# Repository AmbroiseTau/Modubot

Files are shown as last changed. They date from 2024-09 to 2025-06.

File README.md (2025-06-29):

<div style="display: flex; justify-content: center; margin: 0 auto; width: 100%;">
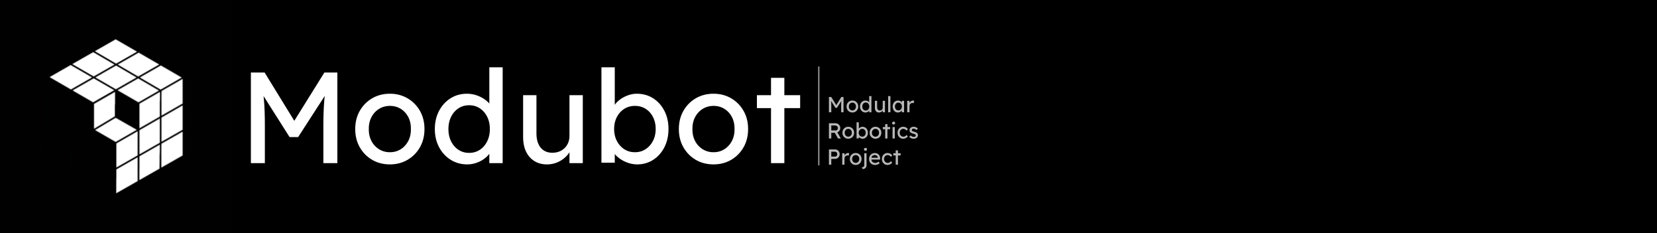
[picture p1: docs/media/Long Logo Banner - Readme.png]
Modubot: A Modular Robotics Project
  
</div>

---

**Modubot** is a modular robotics platform built around **cube-shaped modules**, each with a **dedicated PCB** designed for specific functions. These modules can serve as **regional controllers**, **motor controllers**, **sensor modules**, or other customizable components, allowing for a **flexible and adaptable robotic system**. The entire project is based on **STM32 microcontrollers**.

<div style="display: flex; justify-content: center; margin: 0 auto; width: 100%;">
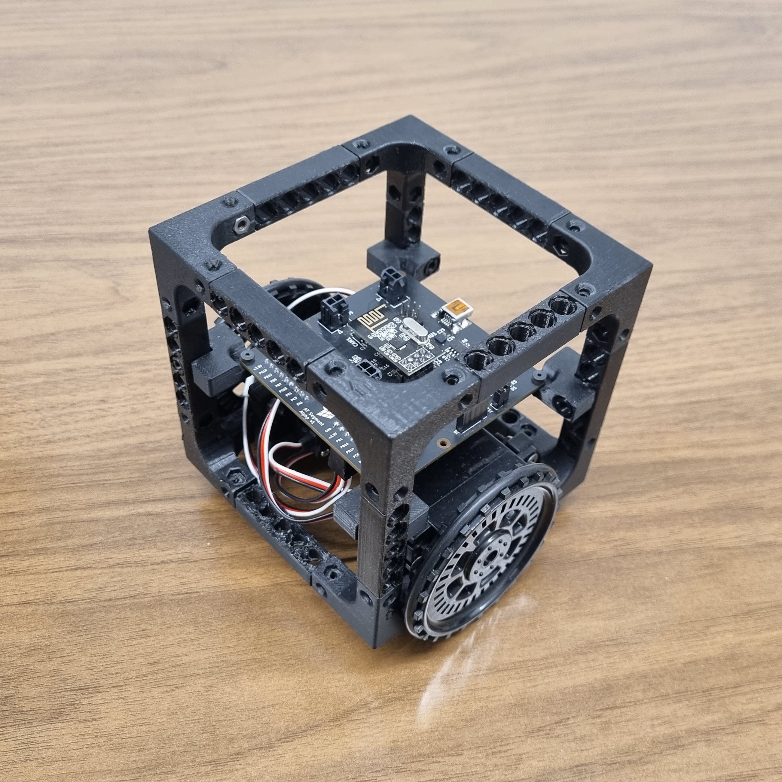
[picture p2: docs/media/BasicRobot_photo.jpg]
  
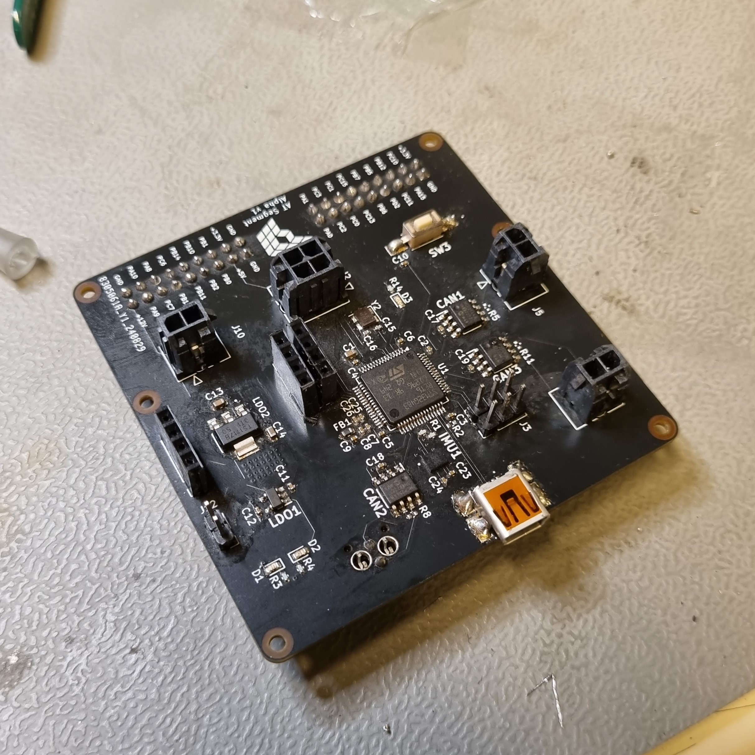
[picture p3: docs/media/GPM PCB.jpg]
  
</div>

---

## **Goal:**

The vision for Modubot is to create a **flexible, modular platform** that promotes **hands-on learning** and **skill development**. By using **cube-based modules**, each with a unique **electronic function**, Modubot acts as a **test platform** for experimenting with:

- **Protocols**
- **Circuits**
- **PCB architecture**
- **Firmware**

This project is a chance to **apply and refine engineering knowledge** while exploring **creative possibilities in robotics**.

---

## **Roadmap:**
1. **✅ Design First Ever Module (General Purpose) - Accomplished**
2. **✅ Create a Simple 2-Wheel Robot with Remote Operation - Accomplished**
3. **✅ Write Firmware for CAN-FD, IMU, UART GPS**
4. **✅ Create a 2 Degrees of Freedom Arm**
5. **🔲 Design a Brushed/Stepper/BLDC Motor Controller Module (MCM)**
6. **🔲 Create a Miniature Buggy Rover**
7. **🔲 Design 2nd Version of the General Purpose Module (GPM)**
8. **🔲 Design Modular Drone (1x GPM + 4x MCM)**

---

## **Current Status:**

### **STAGE 2:**
The current phase features a **2-wheeled robot** designed as a **proof of concept**. It tests the **General Purpose Module (GPM v1)** along with:

- **SPI to NRF24L01** (used for remote control)
- **Servo control**

However, the **continuous servos** faced **tuning issues**, preventing the robot from driving straight, highlighting the need to shift towards **PID-controlled DC motors with encoders** for precise control.

<div style="display: flex; justify-content: center; margin: 0 auto; width: 100%;">
  
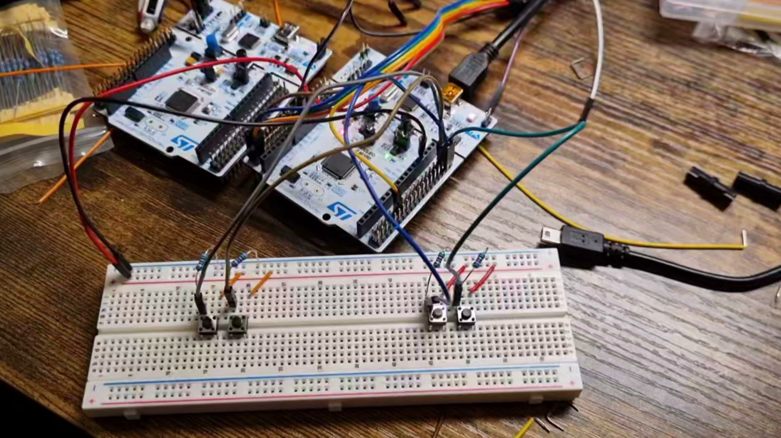
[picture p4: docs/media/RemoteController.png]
  
</div>

---

### **STAGE 1:**
The **first wave of designs** has been completed. The initial **PCB design** was kept **simple** to avoid unnecessary points of failure. It functions as intended, though there are some **design oversights**:

- It cannot handle **high current** (only 1-2 amps at 12V)
- Limited **resistance to back EMF**

These issues will be addressed in **version 2**, after learning more about system requirements.

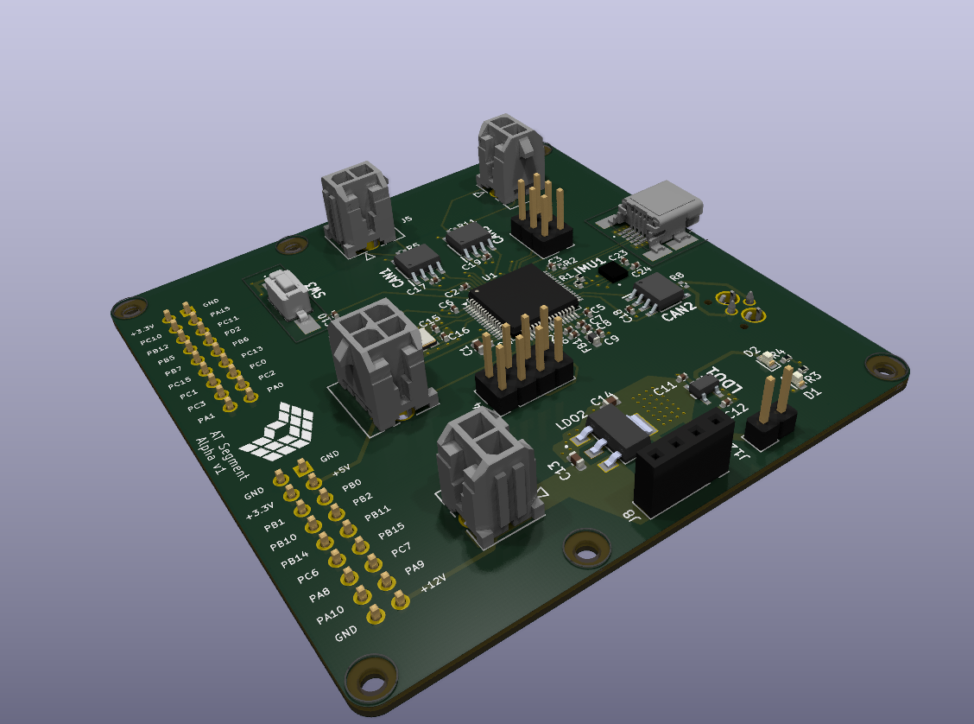
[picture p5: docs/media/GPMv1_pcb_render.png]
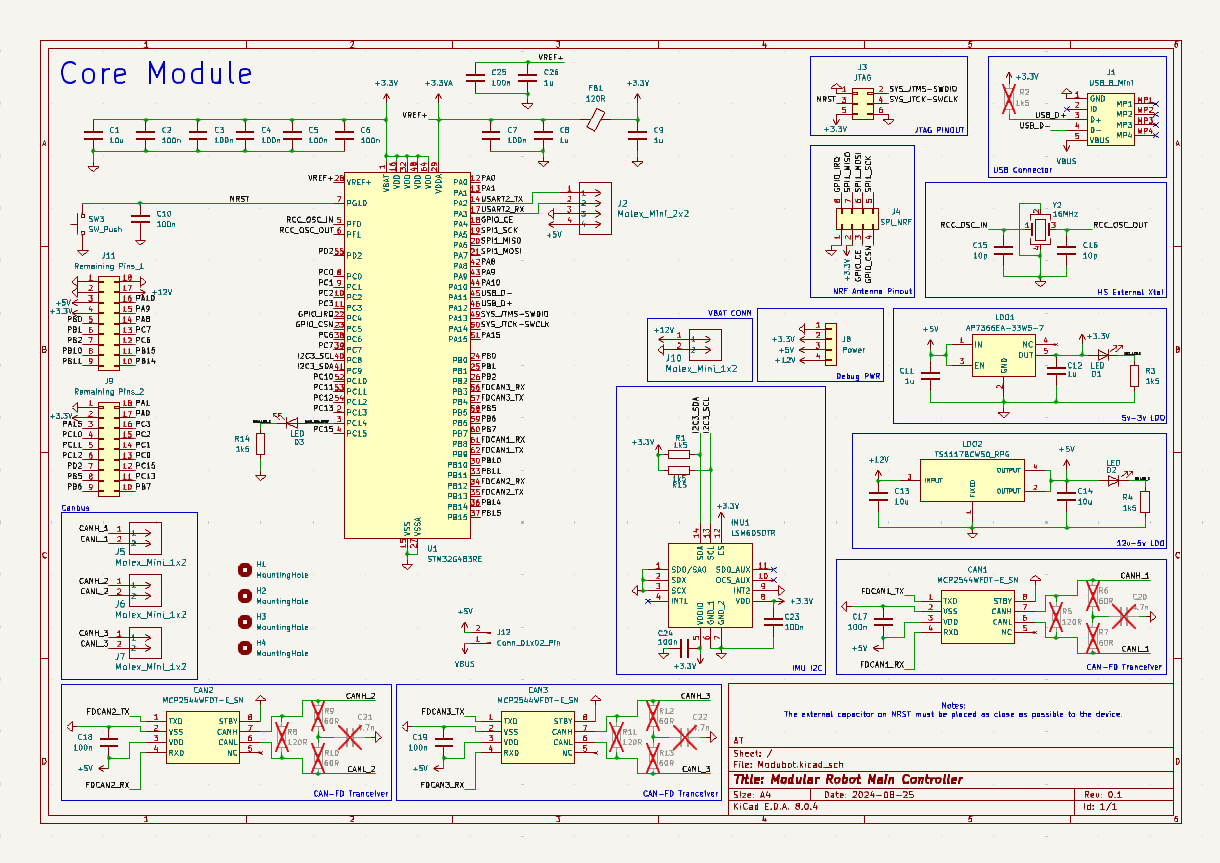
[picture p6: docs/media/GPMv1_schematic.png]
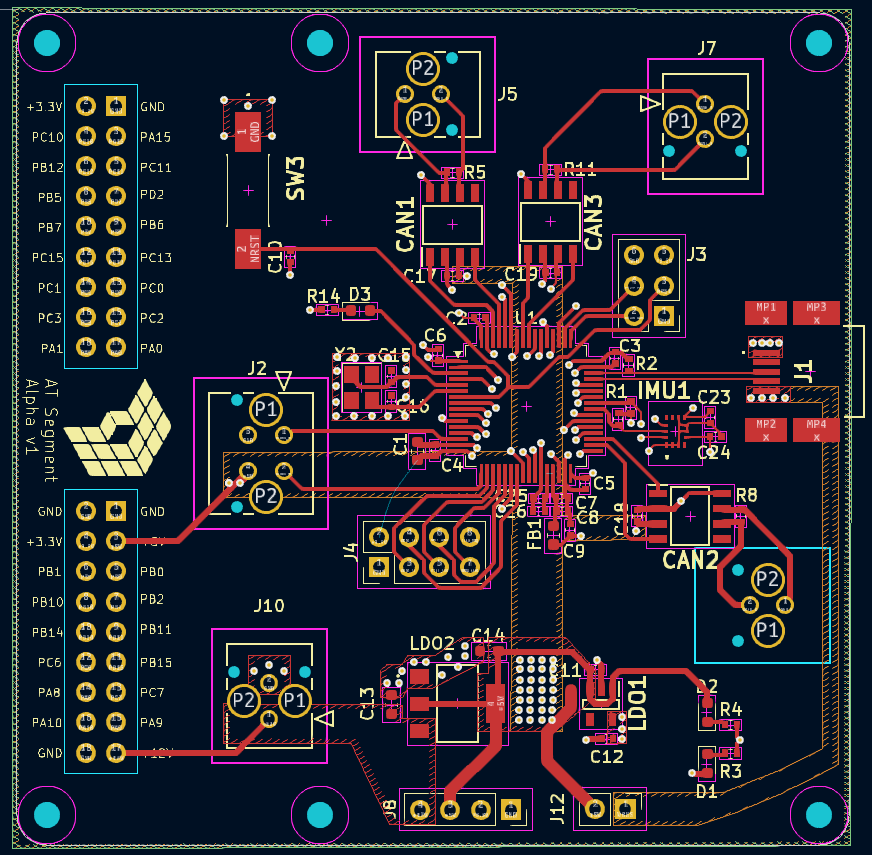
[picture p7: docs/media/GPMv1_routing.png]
   

The **3D-printed structure** has also been refined and is expected to remain unchanged unless major issues arise. For **quick connections** between modules and subcomponents (e.g., PCB bracket), **3D-printed Lego pins (scaled 1.25x)** are being used, and for more **permanent fixtures**, **M6 bolts** can be inserted in the same holes. Initially, **PETG** was used for printing, but due to **brittleness**, the material has been changed to **ABS**, which is more **ductile**.

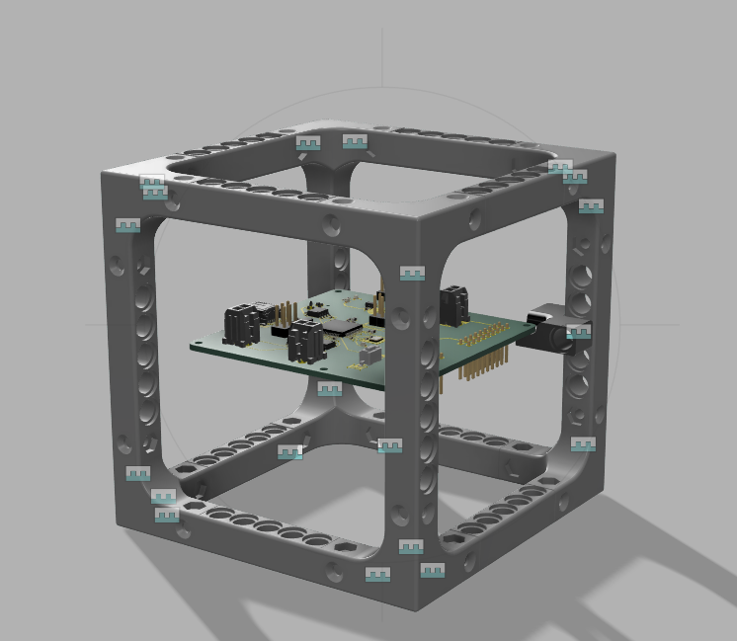
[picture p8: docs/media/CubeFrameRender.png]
CAD of the board


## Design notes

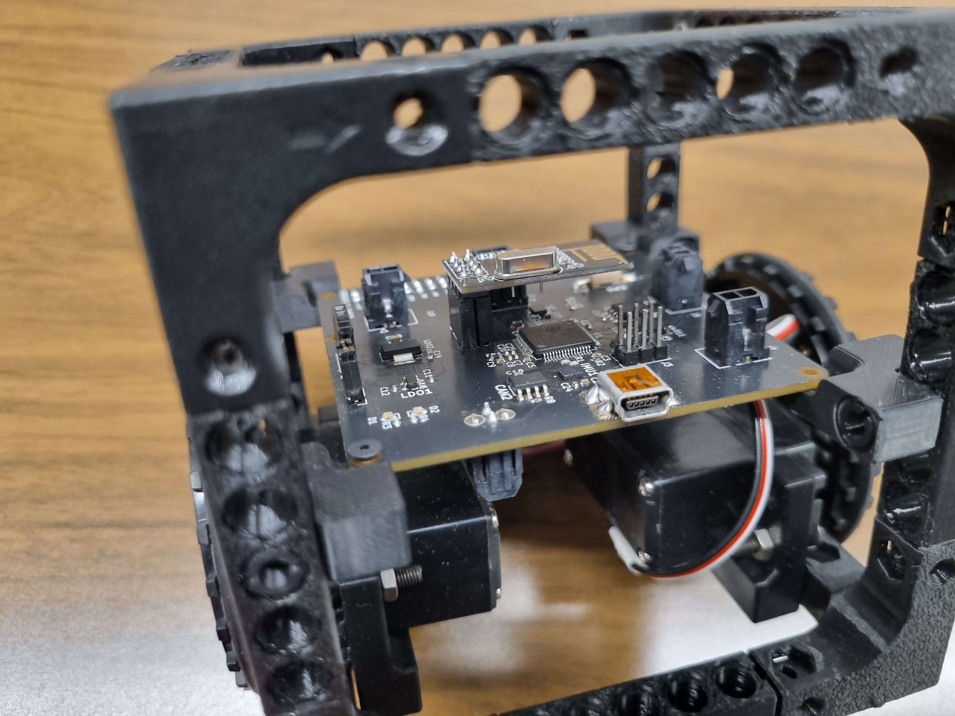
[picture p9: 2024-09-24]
docs/media/Closeup PCB.jpg

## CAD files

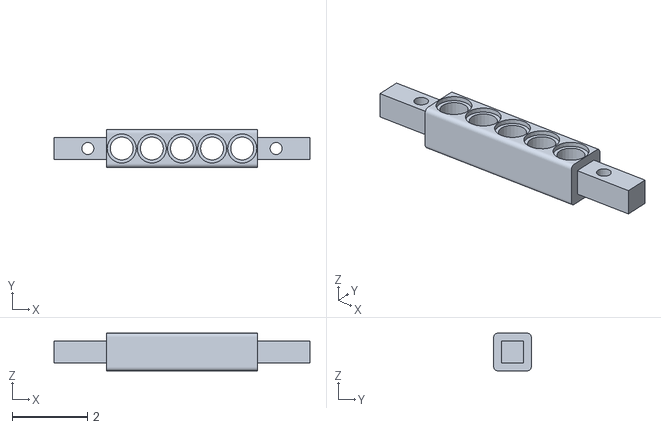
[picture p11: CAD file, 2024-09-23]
GridFrame v1/CAD/Edge Piece - Cube v1.obj
6.80 x 1.00 x 1.00

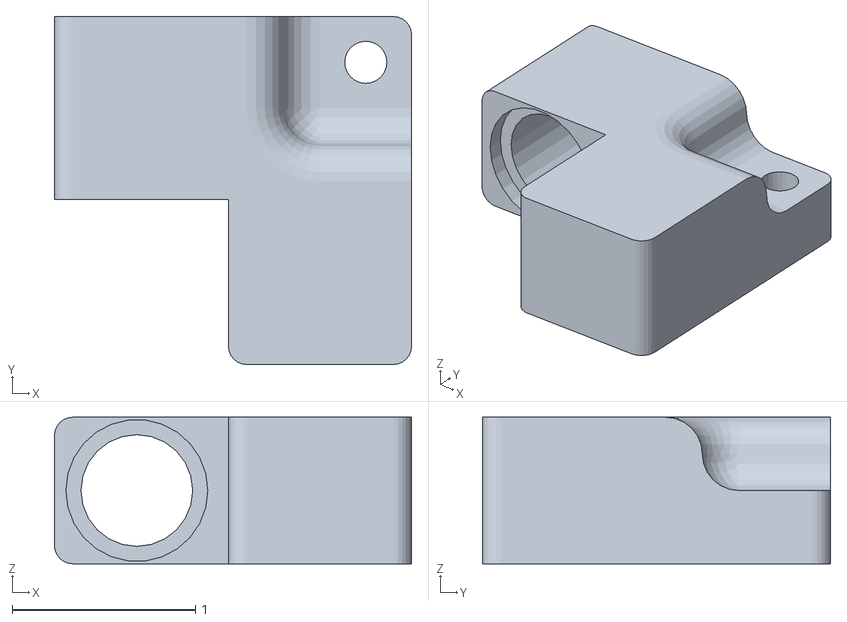
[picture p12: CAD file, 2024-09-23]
GridFrame v1/CAD/Board Bracket - Cube v1.obj
1.95 x 1.90 x 0.8

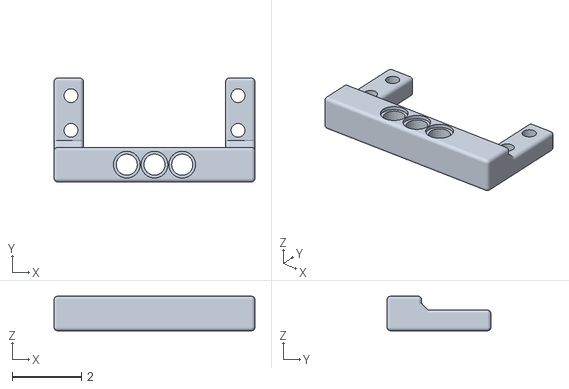
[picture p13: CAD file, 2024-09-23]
GridFrame v1/CAD/Servo Bracket - Cube v1.obj
5.80 x 3.00 x 1.00

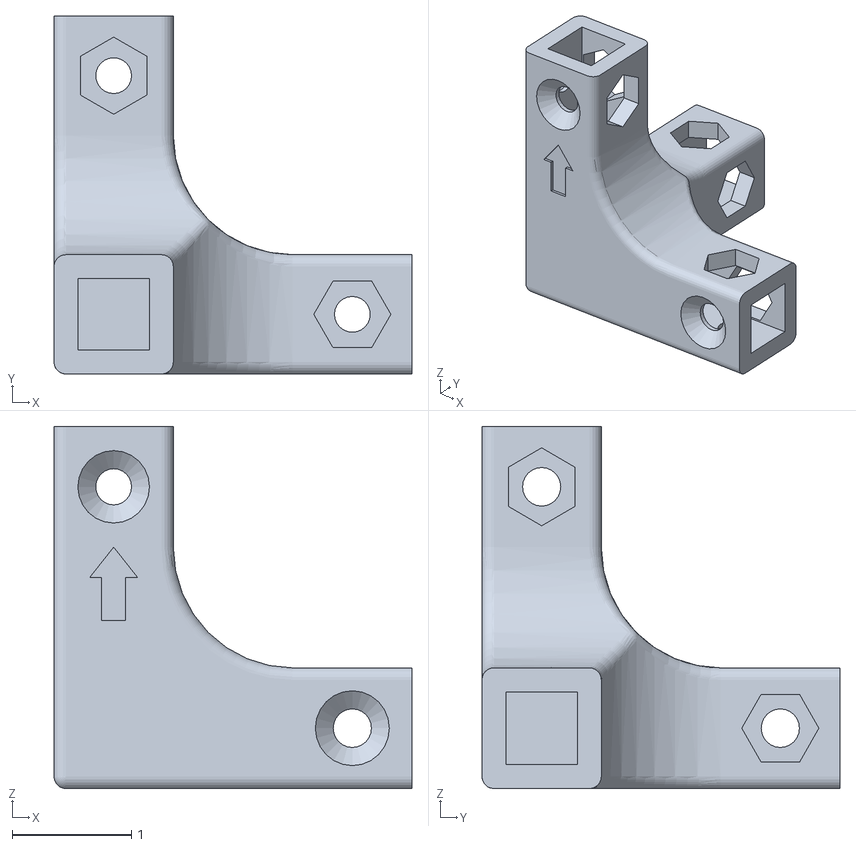
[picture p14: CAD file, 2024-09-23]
GridFrame v1/CAD/Corner Piece - Cube v1.obj
3.00 x 3.00 x 3.03

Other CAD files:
GridFrame v1/CAD/Board Bracket - Cube v1.f3d
GridFrame v1/CAD/Corner Piece - Cube v1.f3d
GridFrame v1/CAD/Edge Piece - Cube v1.f3d
GridFrame v1/CAD/Servo Bracket - Cube v1.f3d

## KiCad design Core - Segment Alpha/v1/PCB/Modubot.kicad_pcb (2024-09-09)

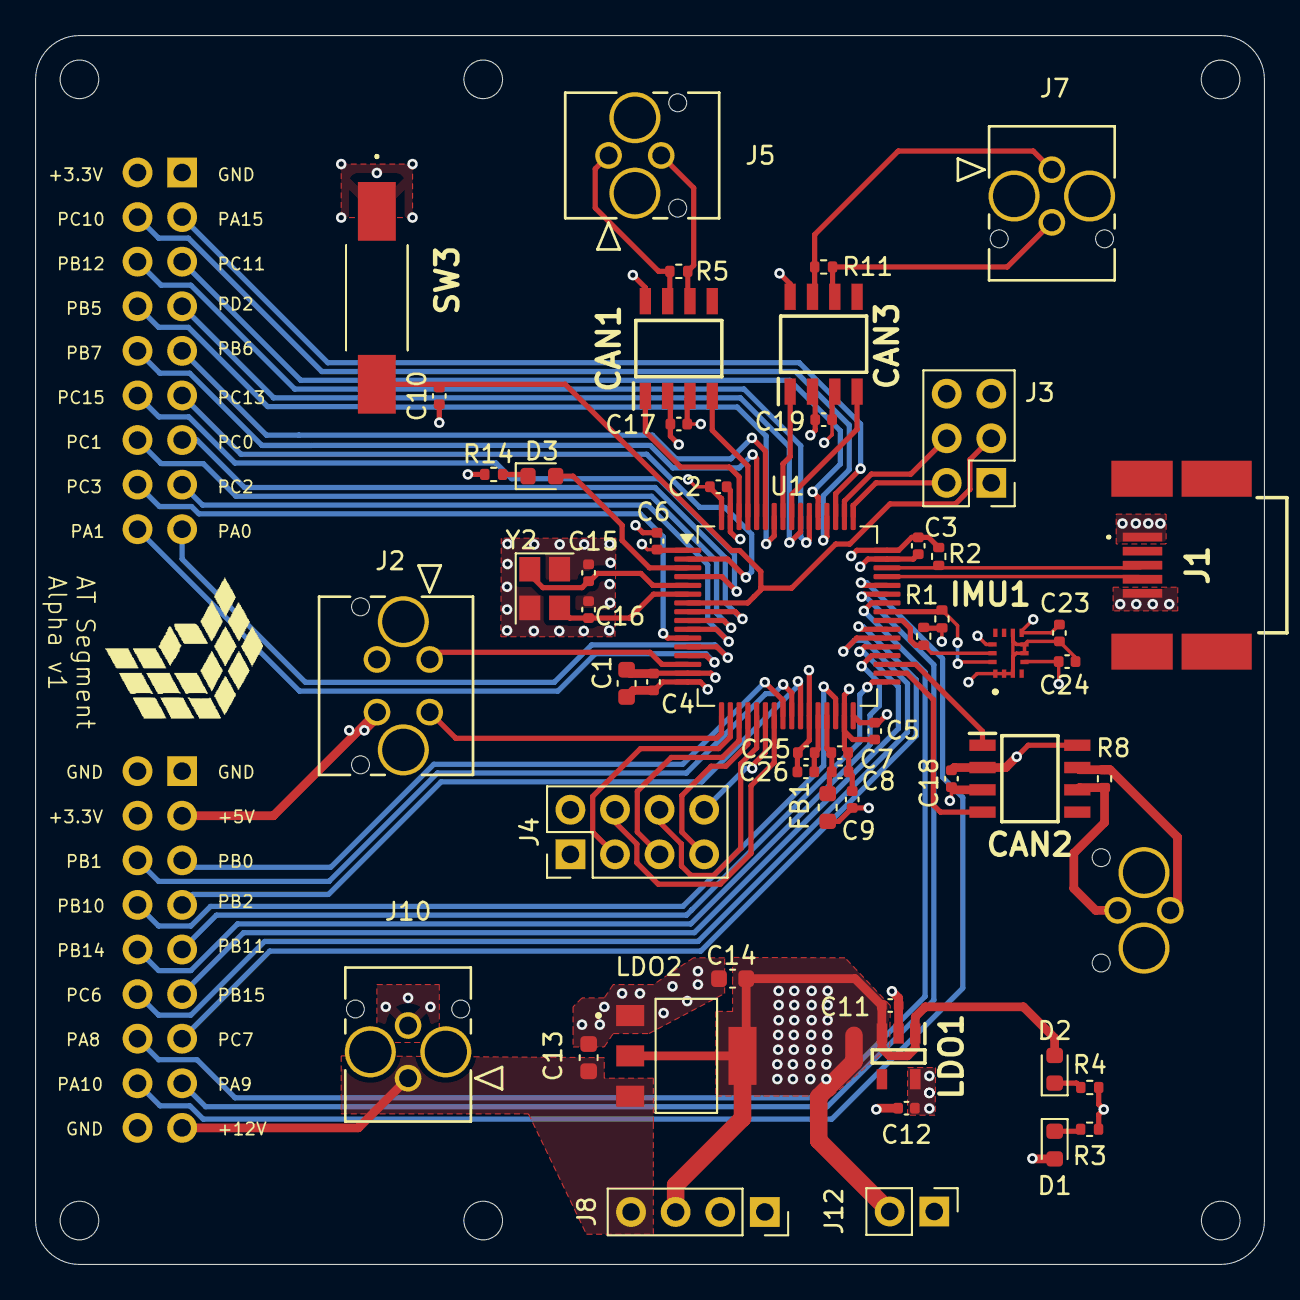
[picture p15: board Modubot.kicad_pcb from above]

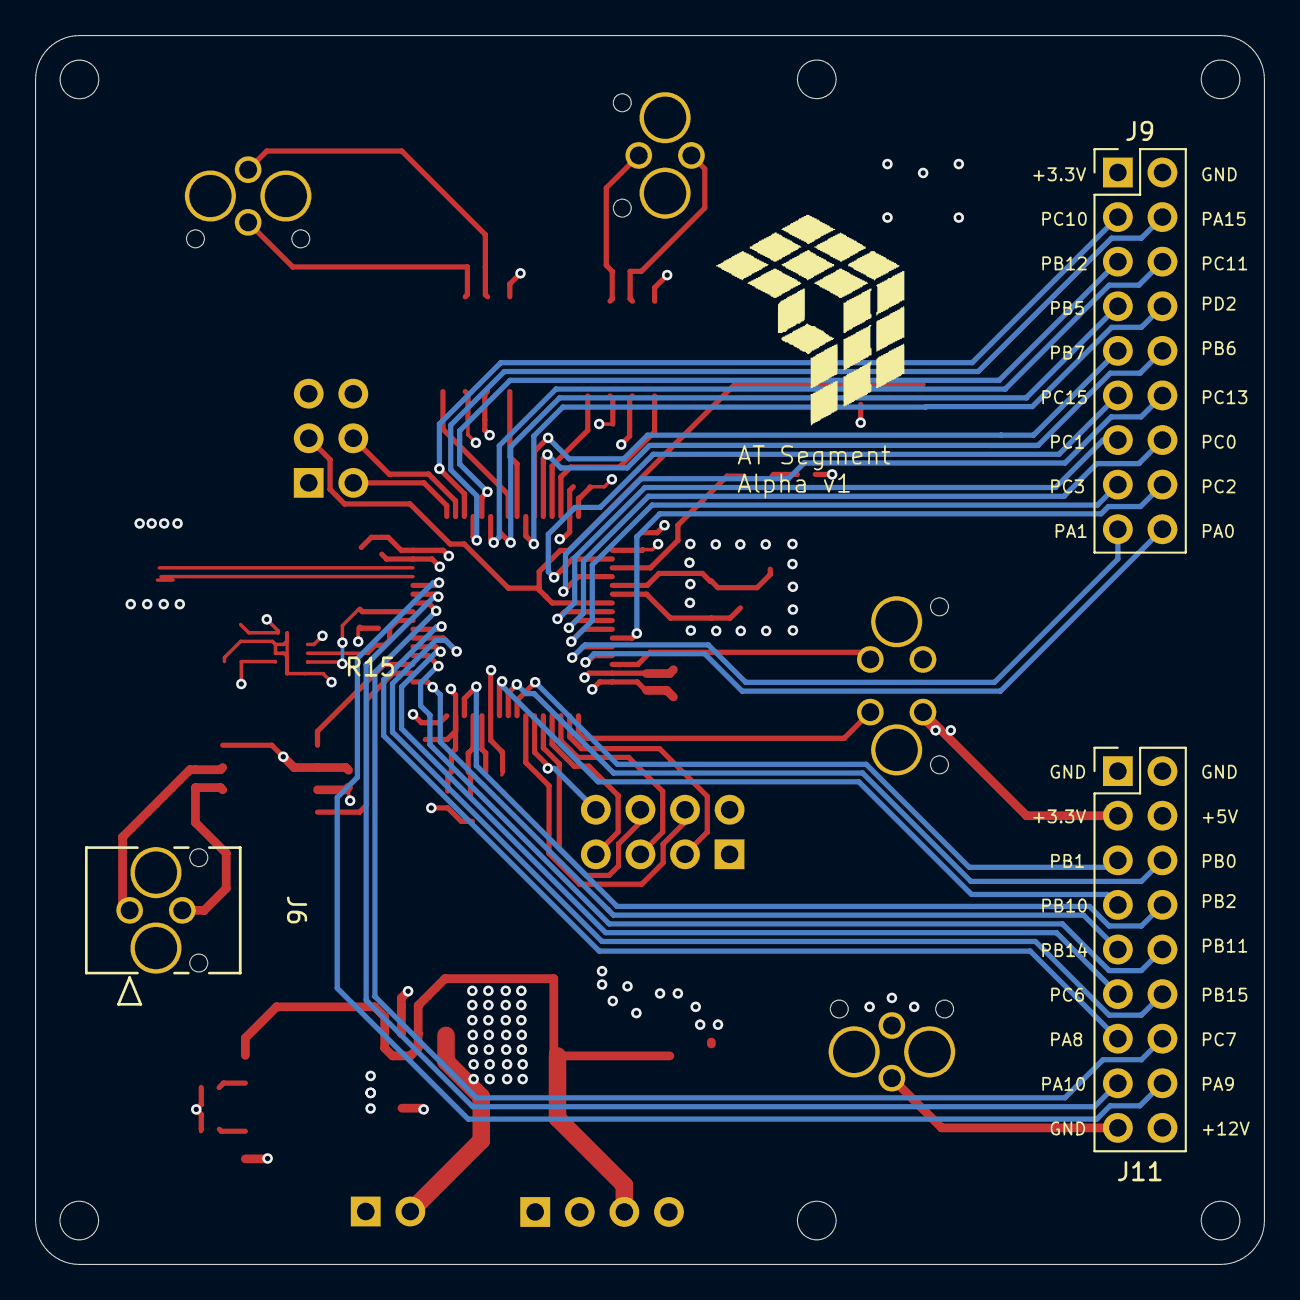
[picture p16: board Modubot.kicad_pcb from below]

Board: 4 copper layers, 70.0 x 70.0 mm, 63 parts (3 on the bottom side), 67 nets.

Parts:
C1, C13, C14: 10u; C_0603_1608Metric
C2, C3, C4, C5, C6, C7, C10, C17, C18, C19, C23, C24, C25: 100n; C_0402_1005Metric
C8, C9, C11, C12, C26: 1u; C_0402_1005Metric
C15, C16: 10p; C_0402_1005Metric
CAN1, CAN2, CAN3: MCP2544WFDT-E_SN; SOIC127P600X175-8N
D1, D2, D3: LED; LED_0603_1608Metric
FB1: 120R; L_0603_1608Metric
H1, H2, H3, H3#2, H4, H4#2: MountingHole; MountingHole_2.2mm_M2
IMU1: LSM6DSOTR; LSM6DS3USTR
J1: USB_B_Mini; 548190572
J2: Molex_Mini_2x2; CON_430450424_MOL_VERT_2x2
J3: JTAG; PinHeader_2x03_P2.54mm_Vertical
J4: SPI_NRF; PinHeader_2x04_P2.54mm_Vertical
J5, J6, J7, J10: Molex_Mini_1x2; CON_430450224_MOL_VERT_1x2
J8: Power; PinSocket_1x04_P2.54mm_Vertical
J9: Remaining Pins_2; PinHeader_2x09_P2.54mm_Vertical
J11: Remaining Pins_1; PinHeader_2x09_P2.54mm_Vertical
J12: Conn_01x02_Pin; PinHeader_1x02_P2.54mm_Vertical
LDO1: AP7366EA-33W5-7; SOT95P285X140-5N
LDO2: TS1117BCW50_RPG; VREG_TS1117BCW50_RPG
R1, R2, R3, R4, R14, R15: 1k5; R_0402_1005Metric
R5, R8, R11: 120R; R_0402_1005Metric
SW3: SW_Push; Button_TL3302AF260QG
U1: STM32G483RE; LQFP-64_10x10mm_P0.5mm
Y2: 16MHz; Crystal_SMD_3225-4Pin_3.2x2.5mm

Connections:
+3.3V: C1.1, C2.1, C3.1, C4.1, C5.1, C6.1, C9.1, C12.1, C23.1, C24.1, D1.2 (A), FB1.1, IMU1.5 (VDDIO), IMU1.8 (VDD), IMU1.12 (CS), J3.5, J4.2, J8.2, J9.2, J11.4, LDO1.5 (OUT), R1.1, R2.1, R15.2, U1.1 (VBAT), U1.16 (VDD), U1.32 (VDD), U1.48 (VDD), U1.64 (VDD)
+3.3VA: C7.1, C8.1, C25.1, C26.1, FB1.2, U1.28 (VREF+), U1.29 (VDDA)
+5V: C11.1, C14.1, C17.2, C18.2, C19.2, CAN1.3 (VDD), CAN2.3 (VDD), CAN3.3 (VDD), D2.2 (A), J2.4, J8.3, J11.3, J12.2, LDO1.1 (IN), LDO1.3 (EN), LDO2.2 (OUTPUT), LDO2.4 (OUTPUT)
+12V: C13.1, J8.4, J10.1, J11.17, LDO2.3 (INPUT)
/3V3_LED_C: D1.1 (K), R3.1
/5V_LED_C: D2.1 (K), R4.1
/CANH_1: CAN1.7 (CANH), J5.1, R5.1
/CANH_2: CAN2.7 (CANH), J6.1, R8.1
/CANH_3: CAN3.7 (CANH), J7.1, R11.1
/CANL_1: CAN1.6 (CANL), J5.2, R5.2
/CANL_2: CAN2.6 (CANL), J6.2, R8.2
/CANL_3: CAN3.6 (CANL), J7.2, R11.2
/FDCAN1_RX: CAN1.4 (RXD), U1.61 (PB8)
/FDCAN1_TX: CAN1.1 (TXD), U1.62 (PB9)
/FDCAN2_RX: CAN2.4 (RXD), U1.34 (PB12)
/FDCAN2_TX: CAN2.1 (TXD), U1.35 (PB13)
/FDCAN3_RX: CAN3.4 (RXD), U1.56 (PB3)
/FDCAN3_TX: CAN3.1 (TXD), U1.57 (PB4)
/GPIO_CE: J4.3, U1.18 (PA4)
/GPIO_CSN: J4.4, U1.23 (PC5)
/GPIO_IRQ: J4.8, U1.22 (PC4)
/I2C3_SCL: IMU1.13 (SCL), R15.1, U1.40 (PC8)
/I2C3_SDA: IMU1.14 (SDA), R1.2, U1.41 (PC9)
/NRST: C10.1, J3.3, SW3.2, U1.7 (PG10)
/PA0: J9.17, U1.12 (PA0)
/PA1: J9.18, U1.13 (PA1)
/PA8: J11.14, U1.42 (PA8)
/PA9: J11.15, U1.43 (PA9)
/PA10: J11.16, U1.44 (PA10)
/PA15: J9.3, U1.51 (PA15)
/PB0: J11.5, U1.24 (PB0)
/PB1: J11.6, U1.25 (PB1)
/PB2: J11.7, U1.26 (PB2)
/PB5: J9.8, U1.58 (PB5)
/PB6: J9.9, U1.59 (PB6)
/PB7: J9.10, U1.60 (PB7)
/PB10: J11.8, U1.30 (PB10)
/PB11: J11.9, U1.33 (PB11)
/PB14: J11.10, U1.36 (PB14)
/PB15: J11.11, U1.37 (PB15)
/PC0: J9.13, U1.8 (PC0)
/PC1: J9.14, U1.9 (PC1)
/PC2: J9.15, U1.10 (PC2)
/PC3: J9.16, U1.11 (PC3)
/PC6: J11.12, U1.38 (PC6)
/PC7: J11.13, U1.39 (PC7)
/PC10: J9.4, U1.52 (PC10)
/PC11: J9.5, U1.53 (PC11)
/PC12: J9.6, U1.54 (PC12)
/PC13: J9.11, U1.2 (PC13)
/PC15: J9.12, U1.4 (PC15)
/PD2: J9.7, U1.55 (PD2)
/RCC_OSC_IN: C15.1, U1.5 (PF0), Y2.1
/RCC_OSC_OUT: C16.1, U1.6 (PF1), Y2.3
/SPI1_MISO: J4.7, U1.20 (PA6)
/SPI1_MOSI: J4.6, U1.21 (PA7)
/SPI1_SCK: J4.5, U1.19 (PA5)
/SYS_JTCK-SWCLK: J3.4, U1.50 (PA14)
/SYS_JTMS-SWDIO: J3.2, U1.49 (PA13)
/USART2_RX: J2.2, U1.17 (PA3)
/USART2_TX: J2.1, U1.14 (PA2)
/USB_D+: J1.3 (D+), R2.2, U1.46 (PA12)
/USB_D-: J1.4 (D-), U1.45 (PA11)
/User_LED_C: D3.1 (K), R14.1
/User_LED_GPIO: D3.2 (A), U1.3 (PC14)
GND: C1.2, C2.2, C3.2, C4.2, C5.2, C6.2, C7.2, C8.2, C9.2, C10.2, C11.2, C12.2, C13.2, C14.2, C15.2, C16.2, C17.1, C18.1, C19.1, C23.2, C24.2, C25.2, C26.2, CAN1.2 (VSS), CAN1.8 (STBY), CAN2.2 (VSS), CAN2.8 (STBY), CAN3.2 (VSS), CAN3.8 (STBY), IMU1.1 (SDO/SA0), IMU1.2 (SDX), IMU1.3 (SCX), IMU1.6 (GND_1), IMU1.7 (GND_2), IMU1.9 (INT2), J1.1 (GND), J2.3, J3.1, J3.6, J4.1, J8.1, J9.1, J10.2, J11.1, J11.2, J11.18, LDO1.2 (GND), LDO2.1 (FIXED), R3.2, R4.2, R14.2, SW3.1, U1.15 (VSS), U1.27 (VSSA), U1.31 (VSS), U1.47 (VSS), U1.63 (VSS), Y2.2, Y2.4
VBUS: J1.5 (VBUS), J12.1
